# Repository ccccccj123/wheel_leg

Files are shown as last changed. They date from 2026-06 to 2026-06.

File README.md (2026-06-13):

# 轮腿机器人复刻项目

这是一个轮腿机器人复刻工程资料仓库，包含主控固件、FOC 电机驱动固件、MATLAB 建模与代码生成文件、硬件电路文件以及 SolidWorks 结构件。项目核心控制思路是：ESP32 主控通过 IMU、CAN 电机反馈和腿部运动学计算机器人状态，再使用 LQR、PID 与 VMC 生成轮电机和关节电机的扭矩/电压指令；底层 STM32 FOC 板接收 CAN 电压指令，完成无刷电机闭环驱动并回传角度和速度。

## 目录结构

```text
.
├── ESP32_WROOM/      # ESP32 主控程序，PlatformIO + Arduino 框架
├── FOC/              # STM32F103C6 + AS5600 FOC 电机驱动工程与立创 EDA 文件
├── Matlab/           # 腿部运动学、VMC、LQR 建模脚本和 MATLAB Coder 输出
├── CTRL/             # ESP32 主控板原理图/PCB JSON 文件
└── SW/               # SolidWorks 结构件和调参参考图片
```

## 主要功能

- ESP32 主控负责系统初始化、传感器读取、CAN 通信、电机指令下发和姿态控制。
- STM32 FOC 节点负责读取 AS5600 编码器、运行 FOC、接收 CAN 目标电压并回传状态。
- MATLAB 脚本用于生成腿部正运动学、速度雅可比、VMC 力矩转换和腿长相关 LQR 反馈矩阵。
- 硬件资料包含主控板和 FOC 板的立创 EDA 标准版文件。
- 结构资料包含车轮、大小腿、底板和适配件等 SolidWorks 零件。

## ESP32 主控固件

工程位置：`ESP32_WROOM/`

开发环境：

- PlatformIO
- Arduino framework
- 开发板配置：`esp32doit-devkit-v1`
- 主要依赖：
  - `electroniccats/MPU6050`
  - `adafruit/Adafruit ADS1X15`
  - `SPI`

入口文件是 `ESP32_WROOM/src/main.cpp`。初始化顺序如下：

1. `Serial_Init()`：串口调试输出。
2. `CAN_Init()`：初始化 ESP32 TWAI/CAN，总线速率 1 Mbps。
3. `IMU_Init()`：初始化 MPU6050 DMP，读取姿态角、角速度和 Z 轴加速度。
4. `Motor_InitAll()`：初始化 6 个电机对象并启动电机指令发送任务。
5. `Legs_Init()`：根据关节角度计算左右腿腿长、腿角和速度。
6. `Ctrl_Init()`：启动目标更新和基础平衡控制任务。

主控模块说明：

| 模块 | 文件 | 说明 |
| --- | --- | --- |
| CAN | `src/can.cpp` | 使用 ESP32 TWAI，接收电机反馈，向左右侧 FOC 板发送电压指令。 |
| Motor | `src/motor.cpp` | 管理 4 个关节电机和 2 个轮电机，做反电动势补偿、电压限幅和 CAN 打包。 |
| IMU | `src/imu.cpp` | 读取 MPU6050 DMP 姿态，维护 yaw 连续角。 |
| Legs | `src/legs.cpp` | 调用 MATLAB 生成函数计算腿部姿态和速度。 |
| Ctrl | `src/ctrl.cpp` | 4 ms 周期控制任务，包含 LQR、PID、VMC 和 yaw/roll/腿长控制。 |
| BLE | `src/ble.cpp` | 预留蓝牙遥控入口，可接收速度、转向速度和腿长目标。当前 `main.cpp` 中未启用。 |
| ADC | `src/adc.cpp` | 使用 ADS1115 读取电池电压，并根据电压调整电机输出比例。当前 `main.cpp` 中未启用。 |
| PID | `src/pid.cpp` | 单级 PID 和串级 PID 工具函数。 |

### ESP32 构建和烧录

进入主控工程目录：

```bash
cd ESP32_WROOM
pio run
pio run -t upload
pio device monitor -b 115200
```

如果使用 VS Code，可以安装 PlatformIO 插件后直接打开 `ESP32_WROOM/`。

## FOC 电机驱动

工程位置：`FOC/C6T6_AS5600/`

硬件和软件特征：

- MCU：STM32F103C6
- 编码器：AS5600
- 电机控制：SimpleFOC 风格的简化实现
- 通信：CAN + USART1 调试
- 工程文件：
  - `C6T6_AS5600.ioc`：STM32CubeMX 配置
  - `MDK-ARM/C6T6_AS5600.uvprojx`：Keil MDK 工程
  - `CMakeLists.txt`：CMake 工程描述

FOC 主循环在 `Core/Src/main.c` 中：

```c
setTargetVotage(targetVotage);
loopFOC();
```

其中 `targetVotage` 来自 CAN 或串口调试命令，最终进入 FOC q 轴电压输出。

关键模块：

| 模块 | 文件 | 说明 |
| --- | --- | --- |
| CAN 协议 | `Motor/mission_can.c` | 接收主控电压指令，回传角度和速度，500 ms 离线保护。 |
| 周期任务 | `Motor/mission_loop.c` | 心跳灯、离线检测、角度滤波、速度估算和状态回传。 |
| 串口调试 | `Motor/mission_uart.c` | 支持设置电机 ID、擦除 Flash、重启、直接设置目标电压和查询电角度。 |
| FOC 核心 | `SimpleFOC/` | BLDC、电角度、SVPWM/FOC 相关实现。 |
| 编码器 | `SimpleFOC/as5600.c` | AS5600 角度读取。 |
| 参数存储 | `Motor/FlashStorage.c` | 保存电机 ID 和标定参数。 |

### FOC 串口调试命令

串口波特率：`115200`

常用命令：

```text
setid:3      # 设置当前 FOC 板电机 ID 为 3，写入 Flash 后自动复位
erase        # 擦除 Flash 参数
reboot       # 软件复位
vot:1000     # 设置目标电压为 1000 mV
angle        # 输出当前电角度
```

### CAN 通信约定

主控发送：

- `0x100`：控制 ID 1~4 的电机。
- `0x200`：控制 ID 5~8 的电机。
- 每台电机占 2 字节，类型为 `int16_t`，单位为 mV。

FOC 回传：

- 回传 ID：`0x100 + motorID`。
- byte 0~3：角度，`int32_t`，单位为 `rad * 1000`。
- byte 4~5：速度，`int16_t`，单位为 `rpm * 10`。

ESP32 当前使用的反馈 ID 映射：

| CAN ID | 电机 |
| --- | --- |
| `0x101` | 左腿关节 0 |
| `0x102` | 左腿关节 1 |
| `0x103` | 左轮 |
| `0x105` | 右腿关节 0 |
| `0x106` | 右腿关节 1 |
| `0x107` | 右轮 |

ESP32 当前发送的控制帧：

- `0x100`：左侧两个关节电机和左轮。
- `0x200`：右侧两个关节电机和右轮。

## MATLAB 建模与代码生成

工程位置：`Matlab/`

核心脚本：

| 文件 | 说明 |
| --- | --- |
| `leg_function.m` | 根据五连杆几何关系生成腿长、腿角、腿部速度和 VMC 转换函数。 |
| `system_calculate.m` | 建立轮腿系统状态空间模型，离散化后求解 LQR，并对不同腿长的反馈矩阵做三次多项式拟合。 |
| `out_leg_position.m` | 腿部正运动学输出。 |
| `out_leg_speed.m` | 腿部速度雅可比输出。 |
| `out_leg_vmc_conv.m` | 将虚拟腿推力和髋关节扭矩转换为两关节电机扭矩。 |
| `out_lqr_k.m` | 根据当前腿长输出 2x6 LQR 反馈矩阵。 |

`Matlab/codegen/` 中包含 MATLAB Coder 生成的 C 代码。ESP32 工程中已拷贝一份到：

```text
ESP32_WROOM/include/matlab_code/
ESP32_WROOM/src/matlab_code/
```

如果修改 MATLAB 模型，需要重新生成 C 代码，并同步更新 ESP32 工程中的 `matlab_code` 文件。

## 硬件资料

### 主控板

目录：`CTRL/`

- `SCH_ESP32_Control_2024-11-08.json`
- `PCB_PCB_ESP32_Control_2024-11-08.json`

这部分是 ESP32 主控板的立创 EDA 工程文件。

### FOC 板

目录：`FOC/`

- `SCH_FocNano_C6T6_AS5600_2024-11-08.json`
- `PCB_PCB_2024-11-08.json`

`FOC/PCB为立创EDA标准版绘制.txt` 表明该 PCB 使用立创 EDA 标准版绘制。

## 结构资料

目录：`SW/`

包含 SolidWorks 零件文件，例如：

- `车轮.SLDPRT`
- `小腿.SLDPRT`
- `适配4310大腿.SLDPRT`
- `重置底板.SLDPRT`
- `飞卡车皮.SLDPRT`
- `调参用相关参数.png`

## 调试和标定注意事项

- 上电前确认电机 ID 和 CAN ID 映射一致，否则主控会把电压发给错误电机。
- FOC 板超过 500 ms 没收到有效 CAN 控制帧会自动把目标电压清零，并点亮离线指示灯。
- ESP32 主控串口波特率为 `115200`，`serial.cpp` 中保留了多组调试输出，可按需要打开。
- MPU6050 的安装方向和偏置会影响姿态控制，`imu.cpp` 中已有一组偏置参数，换硬件后建议重新标定。
- `motor.cpp` 中的关节零位、方向、最大电压和扭矩系数依赖实物测量，换电机或机构后需要重新确认。
- `ctrl.cpp` 当前基础控制周期为 4 ms，CAN 接收和电机发送周期约为 2 ms。
- 开启 BLE 或 ADS1115 电池电压补偿时，需要在 `main.cpp` 中调用对应初始化函数。

## 推荐开发流程

1. 先单独烧录和调试每块 FOC 板，确认 `setid`、`vot`、`angle` 命令工作正常。
2. 用主控 CAN 测试任务或低电压指令确认 CAN 收发和电机 ID 映射。
3. 检查左右关节角度方向、轮电机方向和零位偏置。
4. 确认 MATLAB 生成的腿部运动学输出与实物姿态一致。
5. 再启用平衡控制和腿长/yaw/roll 相关控制。

## 许可

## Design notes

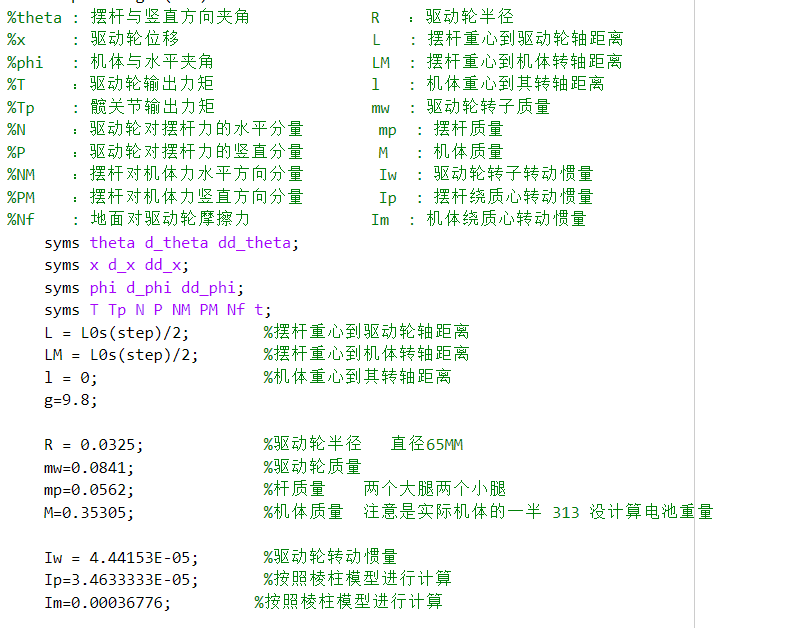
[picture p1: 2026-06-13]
SW/调参用相关参数.png

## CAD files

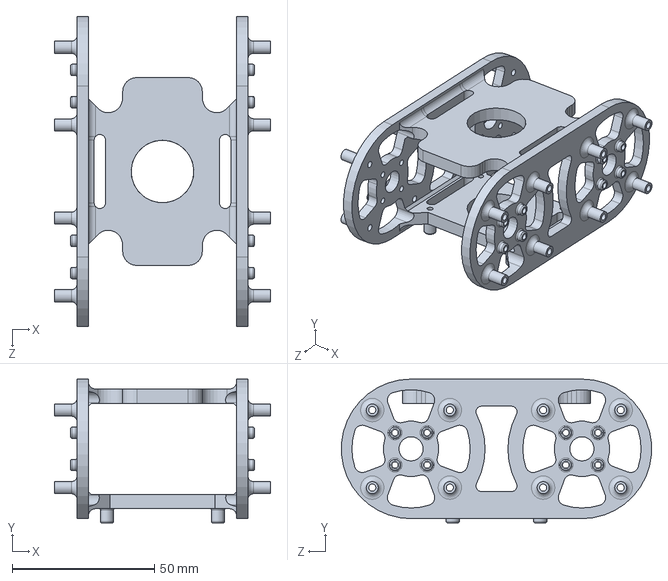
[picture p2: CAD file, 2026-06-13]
SW/重置底板.SLDPRT
76.0 x 50.5 x 108.8 mm

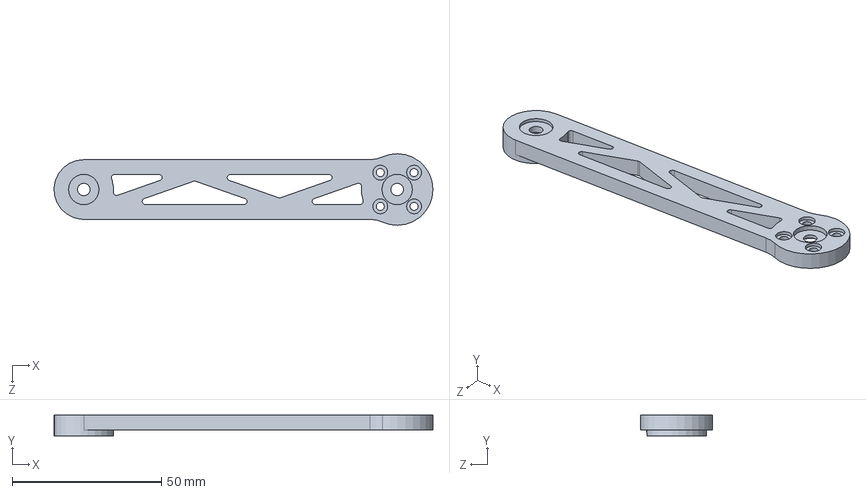
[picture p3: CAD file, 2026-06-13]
SW/小腿.SLDPRT
127.0 x 7.00 x 24.0 mm

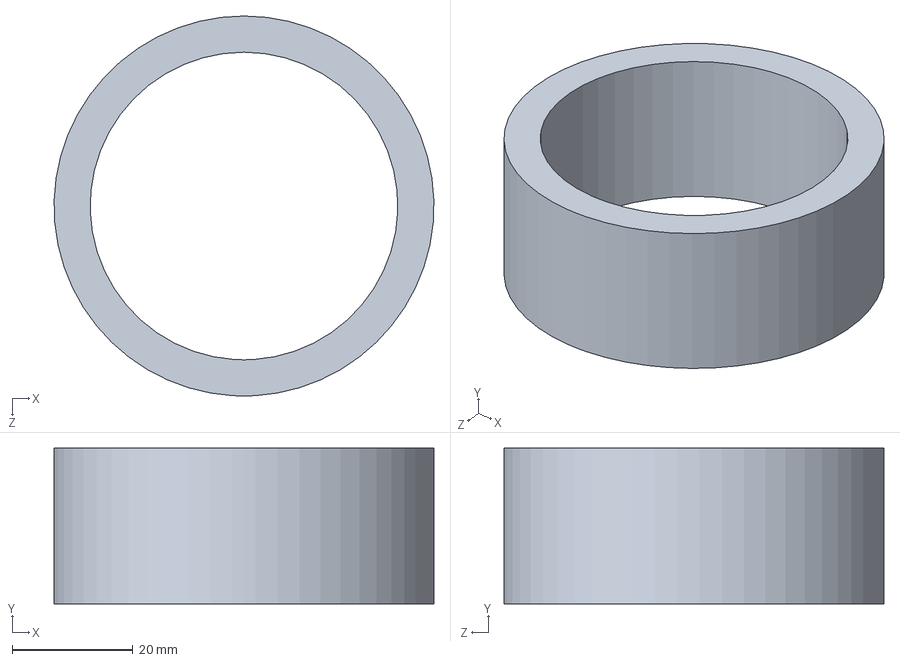
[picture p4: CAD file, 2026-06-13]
SW/飞卡车皮.SLDPRT
63.0 x 25.8 x 63.0 mm

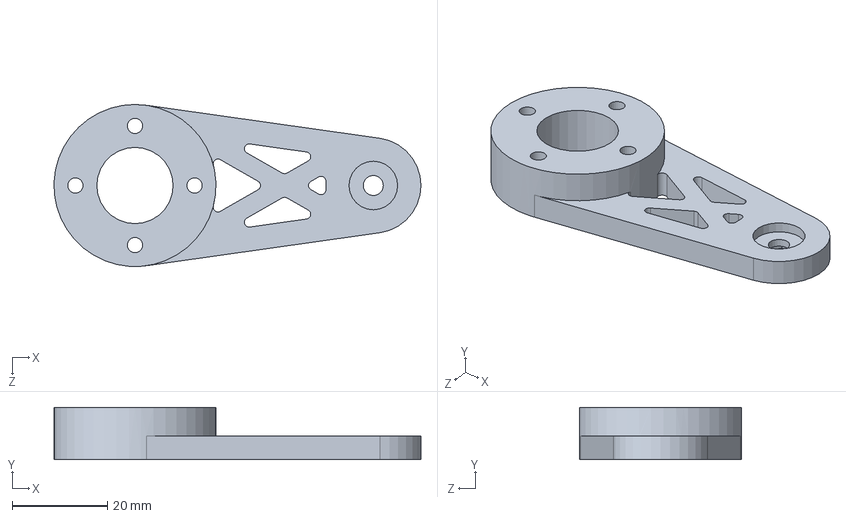
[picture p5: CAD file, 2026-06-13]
SW/适配4310大腿.SLDPRT
77.0 x 11.0 x 34.0 mm

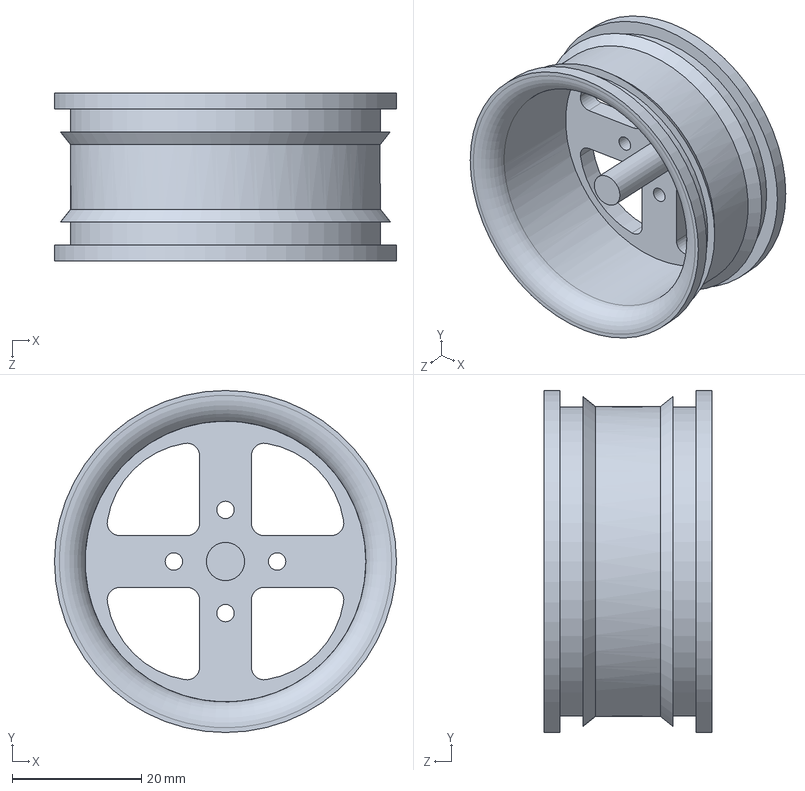
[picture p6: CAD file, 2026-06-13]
SW/车轮.SLDPRT
53.0 x 53.0 x 26.0 mm

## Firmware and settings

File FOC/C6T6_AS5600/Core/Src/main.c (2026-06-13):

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
/* Includes ------------------------------------------------------------------*/
#include "main.h"
#include "can.h"
#include "dma.h"
#include "i2c.h"
#include "tim.h"
#include "usart.h"
#include "gpio.h"

/* USER CODE BEGIN Includes */
#include "as5600.h"
#include "FlashStorage.h"
#include "SimpleKalman.h"
#include "mission_can.h"
#include "BLDCMotor.h"
#include "mission_uart.h"
#include "Beep.h"
/* USER CODE END Includes */


/* USER CODE BEGIN PV */
float targetVotage=0;
/* USER CODE END PV */

void SystemClock_Config(void);
/**
  * @brief  The application entry point.
  * @retval int
  */
int main(void)
{

  /* MCU Configuration--------------------------------------------------------*/

  /* Reset of all peripherals, Initializes the Flash interface and the Systick. */
  HAL_Init();

  /* Configure the system clock */
  SystemClock_Config();

  /* Initialize all configured peripherals */
  MX_GPIO_Init();
  MX_DMA_Init();
  MX_CAN_Init();
  MX_TIM1_Init();
  MX_TIM2_Init();
  MX_USART1_UART_Init();
  MX_I2C1_Init();
  /* USER CODE BEGIN 2 */
  //STM32的IIC通病 可能有BUG 内核重启后IIC可能有概率不工作
  as5600Init();
  
  Kalman_Init(&angleFilter, 0.0005f, 0.1f); 

   motorID = Flash_ReadMotorID(); 
   motorID = motorID ? motorID : 1;
   printf("ID:%1d\r\n",motorID);
//  
//    
  Motor_Init();
  FOC_Init();
  USART_DMA_StartReceive();
  Motor_PlaySong();
  CAN_Init();
  
  /* USER CODE END 2 */

  /* Infinite loop */
  /* USER CODE BEGIN WHILE */
  while (1)
  {
    /* USER CODE END WHILE */

    /* USER CODE BEGIN 3 */
    setTargetVotage(targetVotage);
    loopFOC();
  }
  /* USER CODE END 3 */
}

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


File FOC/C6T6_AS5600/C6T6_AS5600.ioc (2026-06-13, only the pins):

Mcu.UserName=STM32F103C6Tx
PA0-WKUP.Signal=S_TIM2_CH1_ETR
PA1.Signal=S_TIM2_CH2
PA10.Signal=USART1_RX
PA11.Signal=CAN_RX
PA12.Signal=CAN_TX
PA13.Signal=SYS_JTMS-SWDIO
PA14.Signal=SYS_JTCK-SWCLK
PA2.Signal=S_TIM2_CH3
PA3.GPIO_Label=DRV_EN
PA3.Signal=GPIO_Output
PA9.Signal=USART1_TX
PB14.GPIO_Label=ERROR_LED
PB14.Signal=GPIO_Output
PB15.GPIO_Label=LED
PB15.Signal=GPIO_Output
PB6.Signal=I2C1_SCL
PB7.Signal=I2C1_SDA
PD0-OSC_IN.Signal=RCC_OSC_IN
PD1-OSC_OUT.Signal=RCC_OSC_OUT

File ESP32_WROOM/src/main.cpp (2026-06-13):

#include <Arduino.h>
#include "serial.h"
#include "can.h"
#include "imu.h"
#include "motor.h"
#include "ble.h"
#include "legs.h"
#include "ctrl.h"
#include "adc.h"
void setup()
{
//优先级1
Serial_Init();
//优先级4
CAN_Init();
IMU_Init();
Motor_InitAll();
// 优先级2
Legs_Init();
//状态更新优先级3    姿态控制优先级为1 
Ctrl_Init(); 
//蓝牙遥控器捏
//BLE_Init();
}

void loop()
{
}

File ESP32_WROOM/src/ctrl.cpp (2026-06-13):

#include <Arduino.h>
#include "pid.h"
#include "legs.h"
#include "motor.h"
#include "../include/matlab_code/leg_vmc_conv.h"
#include "../include/matlab_code/lqr_k.h"
#include "ctrl.h"
#include "imu.h"
#include <esp_task_wdt.h>
#include <math.h>

CascadePID legAnglePID, legLengthPID; //腿部角度和长度控制PID
CascadePID yawPID, rollPID; //机身yaw和roll控制PID

Target target = {0, 0, 0, 0, 0, 0, 0.07f};
StateVar stateVar;
StandupState standupState = StandupState_Standup;
GroundDetector groundDetector = {10, 10, true, false};	//离地检测器 默认状态为触地
//测试用
#define SIN_FREQUENCY_MS 5000 // 周期，单位毫秒
#define SIN_AMPLITUDE 0.04      // 幅度
#define SIN_OFFSET 0.1         // 偏移量

void vSinGeneratorTask(void *arg) {
    TickType_t xLastWakeTime;
    const TickType_t xFrequency = pdMS_TO_TICKS(SIN_FREQUENCY_MS);

    // 获取当前系统时间
    xLastWakeTime = xTaskGetTickCount();

    while (1) {
        // 计算当前时刻的正弦函数值
        float sin_value = SIN_AMPLITUDE * sin((2 * M_PI * xTaskGetTickCount() / xFrequency))+SIN_OFFSET;
		target.legLength = sin_value; // 假设虚拟腿0的腿部长度为正弦函数值
        // 在这里可以将 sin_value 用于其他操作，比如输出到外设

        // 任务挂起，直到下一个周期
        vTaskDelayUntil(&xLastWakeTime, 5);
    }
}

#define STEP_INTERVAL_MS 1000 // 跃变间隔，单位毫秒
#define STEP_AMPLITUDE 5      // 幅度
// 阶跃函数生成任务
void vStepGeneratorTask(void *pvParameters) {
    TickType_t xLastWakeTime;
    const TickType_t xFrequency = pdMS_TO_TICKS(STEP_INTERVAL_MS);
    int step_value = 0;

    // 获取当前系统时间
    xLastWakeTime = xTaskGetTickCount();

    while (1) {
        // 每隔一定时间改变阶跃函数值
        step_value += STEP_AMPLITUDE;

        // 在这里可以将 step_value 用于其他操作，比如输出到外设

        // 任务挂起，直到下一个跃变间隔
        vTaskDelayUntil(&xLastWakeTime, xFrequency);
    }
}

void VMC_TestTask(void *arg)
{
	float targetLegLength = 0.1f; //m，目标虚拟腿腿部长度 
    float targetLegAngle = 1.57f; //rad，目标虚拟腿腿部角度 1.57 = pai/2  居中

	TickType_t xLastWakeTime = xTaskGetTickCount();

    while (1)
{
	float targetLegLength = target.legLength;
	// //测试左腿
	// float legLength = leftLegPos.length;
	// float dLegLength = leftLegPos.dLength;

	// PID_CascadeCalc(&legLengthPID,targetLegLength,legLength, dLegLength);
	// PID_CascadeCalc(&legAnglePID,targetLegAngle, leftLegPos.angle, leftLegPos.dAngle);
		
	// float leftJointTorque[2]={0};
	// float leftForce = legLengthPID.output;
	// float leftTp =  - legAnglePID.output;
	// leg_vmc_conv(leftForce, leftTp, leftJoint[1].angle, leftJoint[0].angle, leftJointTorque);
	// Motor_SetTorque(&leftJoint[0], -leftJointTorque[0]);
	// Motor_SetTorque(&leftJoint[1], -leftJointTorque[1]);

	//测试右腿
	float legLength = rightLegPos.length;
	float dLegLength = rightLegPos.dLength;

	PID_CascadeCalc(&legLengthPID,targetLegLength,legLength, dLegLength);
	PID_CascadeCalc(&legAnglePID,targetLegAngle, rightLegPos.angle, rightLegPos.dAngle);
		
	float rightJointTorque[2]={0};
	float rightForce = legLengthPID.output;
	float rightTp =   -legAnglePID.output;
	leg_vmc_conv(rightForce, rightTp, rightJoint[1].angle, rightJoint[0].angle, rightJointTorque);
	Motor_SetTorque(&rightJoint[0], -rightJointTorque[0]);
	Motor_SetTorque(&rightJoint[1], -rightJointTorque[1]);

	//测试两条腿捏
	// float legLength = (leftLegPos.length + rightLegPos.length) / 2;
	// float dLegLength = (leftLegPos.dLength + rightLegPos.dLength) / 2;

	// PID_CascadeCalc(&legLengthPID,targetLegLength,legLength, dLegLength);
	// PID_CascadeCalc(&legAnglePID,0, leftLegPos.angle - rightLegPos.angle,  leftLegPos.dAngle - rightLegPos.dAngle);
		
	// float leftJointTorque[2]={0};
	// float leftForce = legLengthPID.output;
	// float leftTp =  - legAnglePID.output;
	// leg_vmc_conv(leftForce, leftTp, leftJoint[1].angle, leftJoint[0].angle, leftJointTorque);

	// float rightJointTorque[2]={0};
	// float rightForce = legLengthPID.output;
	// float rightTp =   + legAnglePID.output;
	// leg_vmc_conv(rightForce, rightTp, rightJoint[1].angle, rightJoint[0].angle, rightJointTorque);

	// Motor_SetTorque(&leftJoint[0], -leftJointTorque[0]);
	// Motor_SetTorque(&leftJoint[1], -leftJointTorque[1]);
	// Motor_SetTorque(&rightJoint[0], -rightJointTorque[0]);
	// Motor_SetTorque(&rightJoint[1], -rightJointTorque[1]);

	vTaskDelayUntil(&xLastWakeTime, 4); //4ms控制周期
}
}

//目标量更新任务(根据蓝牙收到的目标量计算实际控制算法的给定量)
void Ctrl_TargetUpdateTask(void *arg)
{
	TickType_t xLastWakeTime = xTaskGetTickCount();
	float speedSlopeStep = 0.003f;
	while (1)
	{
		//根据当前腿长计算速度斜坡步长(腿越短越稳定，加减速斜率越大)
		float legLength = (leftLegPos.length + rightLegPos.length) / 2;
		speedSlopeStep = -(legLength - 0.07f) * 0.02f + 0.002f;

		//计算速度斜坡，斜坡值更新到target.speed
		if(fabs(target.speedCmd - target.speed) < speedSlopeStep)
			target.speed = target.speedCmd;
		else
		{
			if(target.speedCmd - target.speed > 0)
				target.speed += speedSlopeStep;
			else
				target.speed -= speedSlopeStep;
		}

		//计算位置目标，并限制在当前位置的±0.1m内
		target.position += target.speed * 0.004f;
		if(target.position - stateVar.x > 0.1f)
			target.position = stateVar.x + 0.1f; 
		else if(target.position - stateVar.x < -0.1f)
			target.position = stateVar.x - 0.1f;

		//限制速度目标在当前速度的±0.3m/s内
		if(target.speed - stateVar.dx > 0.3f)
			target.speed = stateVar.dx + 0.3f;
		else if(target.speed - stateVar.dx < -0.3f)
			target.speed = stateVar.dx - 0.3f;

		//计算yaw方位角目标
		target.yawAngle += target.yawSpeedCmd * 0.004f;
		
		vTaskDelayUntil(&xLastWakeTime, 4); //每4ms更新一次
	}
}
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

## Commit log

2026-06-13 轮腿存档
    [小腿.SLDPRT, 车轮.SLDPRT, 适配4310大腿.SLDPRT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]
2026-06-13 添加readme

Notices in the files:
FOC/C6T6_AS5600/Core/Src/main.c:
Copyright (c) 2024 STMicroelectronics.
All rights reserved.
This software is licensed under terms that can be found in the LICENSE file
